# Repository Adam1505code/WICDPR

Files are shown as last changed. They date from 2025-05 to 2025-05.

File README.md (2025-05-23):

# WICDPR: Winch-Integrated Cable-Driven Parallel Robots for Agriculture

## Project Overview

This repository contains the full open-source hardware, software, and documentation for both 2D and 3D Winch-Integrated Cable-Driven Parallel Robots (WICDPRs).  
These robots are designed for rapid deployment and high-precision motion in agricultural environments (e.g., greenhouses, field plots), minimizing soil compaction and maximizing flexibility by keeping all winches on the mobile platform.
## System Features

- **2D and 3D platforms:** Planar and spatial robots for different workspace needs.
- **Real-time feedback:** Rotary encoders and MPU6050 IMU for position and tilt.
- **Double-loop PID control:** Ziegler–Nichols tuned, with auto-leveling.
- **Teleoperation:** Manual control using ROS teleop nodes.
- **Safety:** E-stop support, tension checks, WiFi router for secure SSH.
- **Comprehensive docs:** Bills of Materials (BOM), STL files, wiring diagrams, and demo videos.

# Getting Started: Step-by-Step Setup for WICDPR

## 1. Hardware Assembly

### 2D System

1. **Print all required STL parts** (see [`docs/stl/`](docs/stl/)).
2. **Assemble the frame** with PETG parts, plywood sheets, M3 and M4 bolts, and ball bearings.
3. **Install NEMA-17 stepper motors and planetary gearboxes** as per mechanical drawings.
4. **Mount both rotary encoders** to the winch spools; ensure pull-up resistor adapters are installed.
5. **Attach the IMU (MPU6050)** securely on the platform for accurate roll/pitch sensing.
6. **String the braided fishing line** through all pulleys and attach to the anchors.
7. **Double-check all power and signal connections** using the wiring diagram.
8. **[Optional]** Place test load (marbles) on platform for load/stability testing.

> 2D Platform Render
> *Figure: 2D Platform CAD Render*

---

### 3D System

1. **Print and assemble all 3D parts** for platform, winch modules, and mounting brackets.
2. **Mount all four DC geared motors** and rotary encoders (DFRobot SEN0230) to winch modules.
3. **Install the IMU (MPU6050)** on the platform.
4. **Set up the winch pods** at each platform corner with swivel/lazy-susan bearings.
5. **String 20m of braided fishing line** for each cable, tension and secure at anchor points.
6. **Connect all electronics:**  
   - Arduino Mega (motor board), Arduino Uno (sensor board)
   - Dual 7A DC motor drivers (DFRobot DRI0041)
   - Pull-up adapters on each encoder
7. **Wire up power supplies, Pi 4, and WiFi router.**

> 3D Platform Assembly
> *Figure: 3D Platform with Electronics*

---

## 2. Electronics and Firmware

1. **Flash the sensor node code** (`arduino/arduino_encoder_revised.ino`) to the Arduino Uno.
2. **Flash the motor node code** (e.g., `arduino_motor_3d.ino` for 3D, or the correct 2D sketch) to the Arduino Mega (3D) or second Uno (2D).
3. **Insert formatted 64GB microSD cards** into the Pi(s).
4. **Power on all electronics** and connect Arduinos and Pi via USB cables.

---

## 3. Raspberry Pi and ROS Setup

1. **Connect the Pi to your WiFi router** (built-in or TP-Link USB adapter).
2. **SSH into the Pi** from your PC using its IP address:
   
   `ssh pi@<your_pi_ip_address>`
3. Source the ROS Noetic environment:
   `source /opt/ros/noetic/setup.bash`
4. Install all Python requirements:
   `pip3 install -r requirements.txt`
5. Start ROS core:
    `roscore`
6. Start ROS serial communication with the first Arduino:
    `rosrun rosserial_python serial_node.py _port:=/dev/ttyUSB0 _baud:=57600`
   
8. Start ROS serial communication with the second Arduino:
   `rosrun rosserial_python serial_node.py _port:=/dev/ttyUSB1 _baud:=57600`
   
10. Run the 2D WICDPR controller node:
    `python3 scripts/cable_platform_2d_controller.py`
    
12. Run the 3D WICDPR controller node:
   `python3 scripts/cable_platform_3d_controller.py`

10.Run 2D teleoperation:
   `python3 scripts/teleop_controller_2D.py`
   
11.Run 3D teleoperation:
    `python3 scripts/teleop_controller_3D.py`

## Bill of Materials (BOM)

- [2D_WICDPR_BOM.xlsx](docs/2D_WICDPR_BOM.xlsx)
- [3D_WICDPR_BOM.xlsx](docs/3D_WICDPR_BOM.xlsx)

*All components, suppliers, and links are included. Please check the BOM before assembly.*

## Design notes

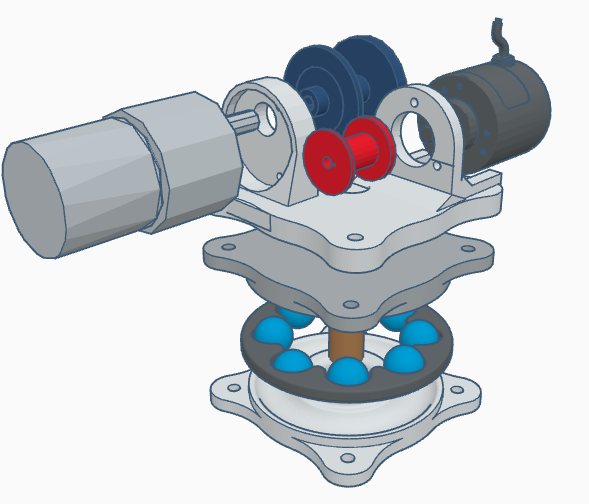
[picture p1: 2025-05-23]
doc/diagrams/Isometric_view_of_winch_design.png

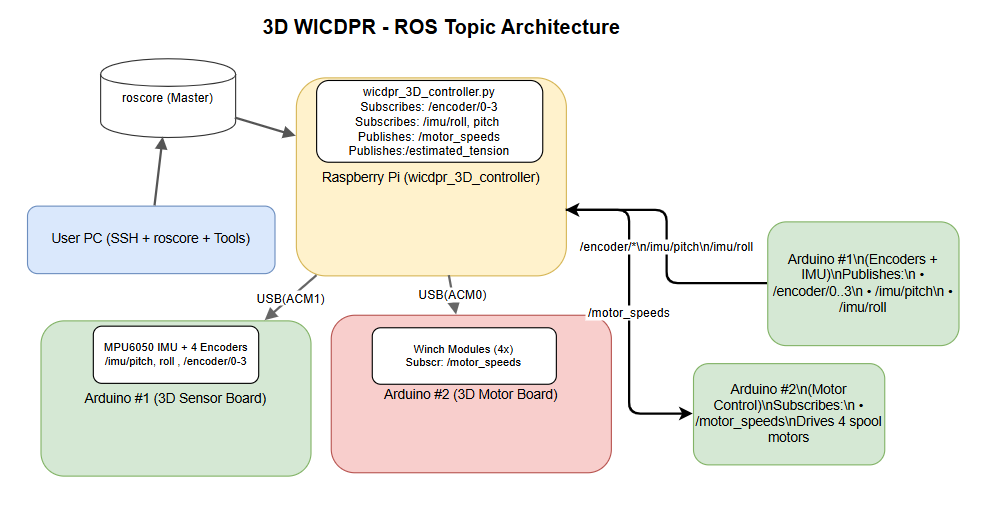
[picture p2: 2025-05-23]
doc/diagrams/ros_architecturefor3D.png

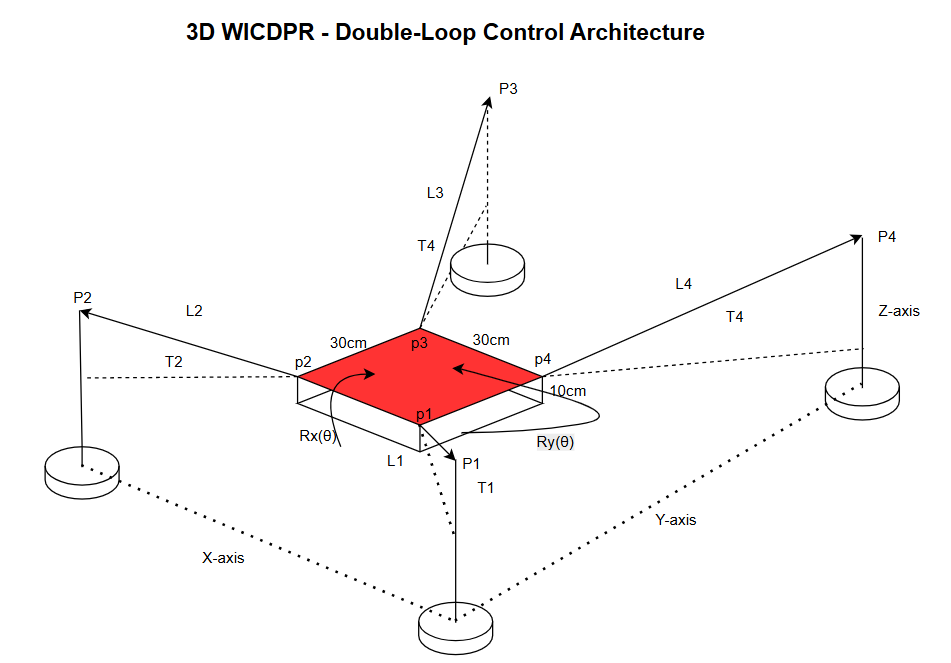
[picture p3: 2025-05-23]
doc/diagrams/Kinematics_of_the_3D_system.png

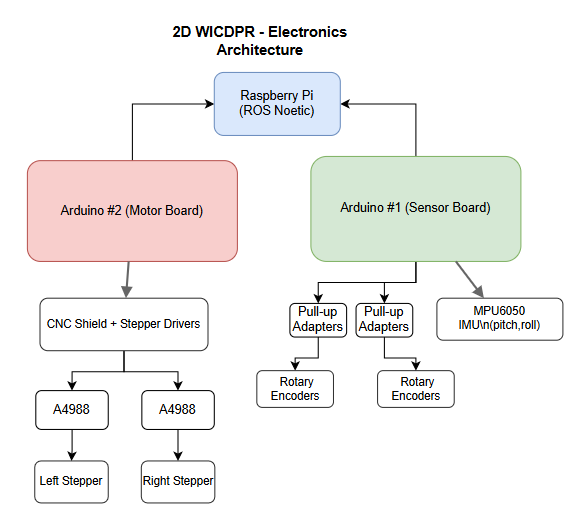
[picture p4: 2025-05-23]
doc/diagrams/2D_WICPDR.png

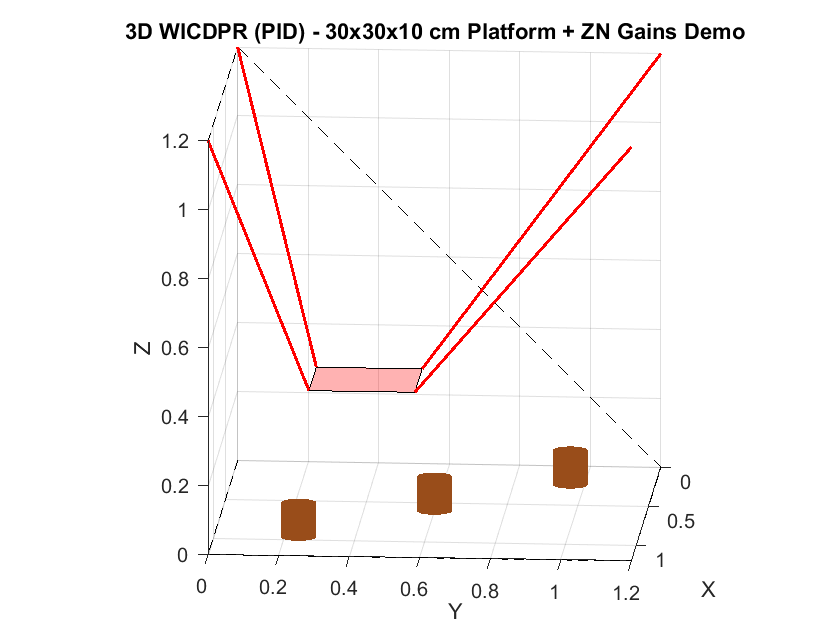
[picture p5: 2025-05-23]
doc/diagrams/ideal_response_of_3d_system.png

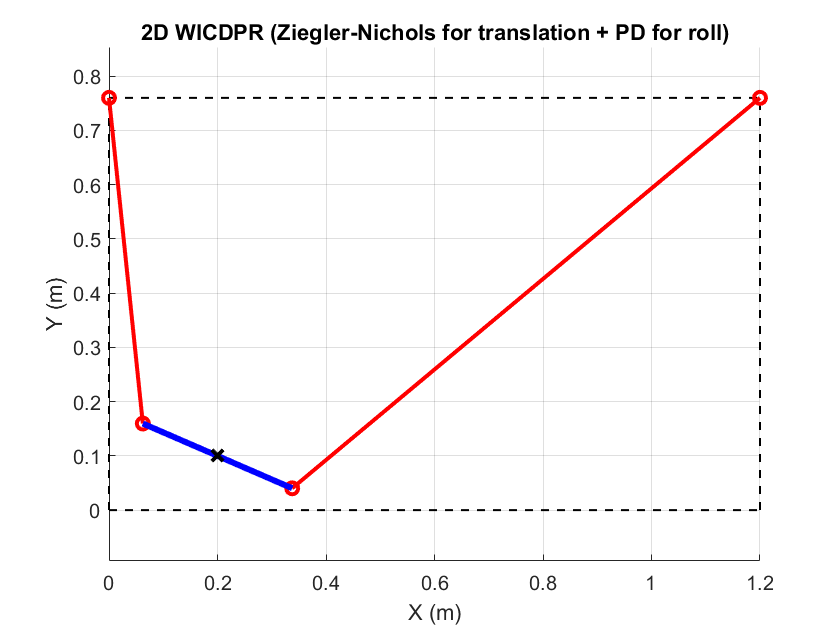
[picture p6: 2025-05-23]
doc/diagrams/2D Simulation.png

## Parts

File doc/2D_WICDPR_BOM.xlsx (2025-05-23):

Component | Quantity | Supplier/Link | Notes/Source
PETG Filament | 1.1 kg | https://www.amazon.com/s?k=petg+filament | 3D printed frame and parts
M3 Bolts and Washers | 24 | https://www.amazon.com/s?k=m3+bolts+and+washers | For frame/platform assembly
NEMA-17 Stepper Motor + Planetary Gearbox + CNC Shield + A4988 + Cables (Kit) | 1 kit | https://www.amazon.co.uk/Professional-Printer-CNC-Shield-Expansion-Engraving/dp/B0D65MFN4V/ | Motors, drivers, cables, shield
Arduino Uno (RS) | 2 | https://uk.rs-online.com/web/p/processor-microcontroller-development-kits/7697414 | Motor node + sensor node
Photoelectric Rotary Encoder (DFRobot SEN0230) | 2 | https://wiki.dfrobot.com/Incremental_Photoelectric_Rotary_Encoder_-_400P_R_SKU__SEN0230 | Cable length feedback
Pull-up Resistor Adapter | 2 | https://www.dfrobot.com/product-1626.html | For each encoder
Ball Bearing | 8 | https://www.amazon.com/s?k=ball+bearing+608zz | For drum/axle support
Braided Hercules Fishing Line | 10 m | https://www.amazon.com/HERCULES-Braided-Fishing-Tension-100lb-109yds/dp/B01J4MHR50 | Main cable, 0.1–0.3mm
Raspberry Pi 3B+ | 1 | https://www.raspberrypi.com/products/raspberry-pi-3-model-b-plus/ | ROS master/controller
TP-Link WiFi Adapter (USB) | 1 | https://www.amazon.com/s?k=tp-link+wifi+adapter | For Pi wireless/SSH
USB Cable (Arduino to Pi) | 2 | https://www.amazon.com/AmazonBasics-USB-2-0-Cable-Male/dp/B00NH11KIK | Arduino <-> Pi
Raspberry Pi Power Supply (USB-C) | 1 | https://www.amazon.com/s?k=raspberry+pi+usb-c+power+supply | 5V 3A
M4 Bolts | 20 | https://www.amazon.com/s?k=m4+bolts | Frame, assembly
DC Barrel Jack Pigtail (5.5mm x 2.1mm) | 1 | https://www.amazon.com/Male-Female-Barrel-Connector-Adapter/dp/B07YCK13BV | For power adapters
Plywood Sheet (30cm x 10cm x 8mm) | 2 | https://www.homedepot.com/p/Handprint-1-4-in-x-2-ft-x-4-ft-Sande-Plywood-25379/206883644 | Platform and frame
IMU (MPU6050) | 1 | https://www.amazon.co.uk/AZDelivery-MPU-6050-Gyroscope-Accelerometer-including/dp/B07TKLYBD6 | For roll/pitch feedback
SanDisk 64GB microSDXC (for Raspberry Pi) | 2 | https://www.amazon.co.uk/SanDisk-Extreme-microSDXC-RescuePRO-Performance/dp/B09X7C7LL1/ref=sr_1_6 | For Raspberry Pi OS, ROS, and data logging
WiFi Router (Dual-Band) | 1 | https://www.amazon.co.uk/s?k=wifi+router | For secure SSH and remote ROS access to Raspberry Pi
Marbles | 1 bag | Art & Hobby | For platform load test

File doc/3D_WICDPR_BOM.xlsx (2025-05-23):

Component | Quantity | Supplier/Link | Notes/Source
12V Metal DC Geared Motor with Encoder (131:1, 83RPM) | 4 | https://www.dfrobot.com/product-633.html | Main winch actuator, with encoder
Incremental Photoelectric Rotary Encoder (DFRobot SEN0230) | 4 | https://wiki.dfrobot.com/Incremental_Photoelectric_Rotary_Encoder_-_400P_R_SKU__SEN0230 | Cable length feedback
Pull-up Resistor Adapter for Sensors | 6 | https://www.dfrobot.com/product-1626.html | For encoder signal integrity
Dual 7A DC Motor Driver Board (DFRobot DRI0041) | 2 | https://wiki.dfrobot.com/7A_Dual_DC_Motor_Driver_SKU__DRI0041 | Drives two DC motors each
IMU (MPU6050 Gyroscope + Accelerometer) | 2 | https://www.amazon.co.uk/AZDelivery-MPU-6050-Gyroscope-Accelerometer-including/dp/B07TKLYBD6 | For platform orientation
Arduino Mega 2560 (RS) | 1 | https://uk.rs-online.com/web/p/processor-microcontroller-development-kits/6961662 | Motor controller node
Arduino Uno (RS) | 1 | https://uk.rs-online.com/web/p/processor-microcontroller-development-kits/7697414 | Sensor node
Raspberry Pi 4B+ | 1 | https://www.raspberrypi.com/products/raspberry-pi-4-model-b/ | ROS master/controller
Raspberry Pi Power Supply (USB-C, 5V 3A) | 1 | https://www.amazon.com/s?k=raspberry+pi+usb-c+power+supply | For Pi
TP-Link WiFi Adapter (USB) | 1 | https://www.amazon.com/s?k=tp-link+wifi+adapter | For Pi wireless/SSH
Power Supply for Motors (12V 6A or 24V 10A) | 1 | https://www.amazon.com/s?k=12v+6a+power+supply | Main supply for winches
Ball Bearing | 8 | https://www.amazon.com/s?k=ball+bearing+608zz | For winch drums
Braided Hercules Fishing Line | 20 m | https://www.amazon.co.uk/HERCULES-100m-2000m-10lb-300lb-Multifilament-Freshwater/dp/B0791F5XJG?th=1 | Main cable, 0.1–0.3mm, >650N
Plywood Sheet (30cm x 30cm x 8mm) | 1 | https://www.homedepot.com/p/Handprint-1-4-in-x-2-ft-x-4-ft-Sande-Plywood-25379/206883644 | Platform deck
PETG Filament | 1.2 kg | https://www.amazon.com/s?k=petg+filament | 3D printed parts
M3 Bolts and Washers | 24 | https://www.amazon.com/s?k=m3+bolts+and+washers | For frame and mounts
Swivel/Lazy-Susan Bearing | 4 | https://www.amazon.com/s?k=lazy+susan+bearing | For winch mounts
USB Cable (A-B for Arduino) | 2 | https://www.amazon.com/AmazonBasics-USB-2-0-Cable-Male/dp/B00NH11KIK | Arduino <-> Pi
SanDisk 64GB microSDXC (for Raspberry Pi) | 2 | https://www.amazon.co.uk/SanDisk-Extreme-microSDXC-RescuePRO-Performance/dp/B09X7C7LL1/ref=sr_1_6 | For Raspberry Pi OS, ROS, and data logging
WiFi Router (Dual-Band) | 1 | https://www.amazon.co.uk/s?k=wifi+router | For secure SSH and remote ROS access to Raspberry Pi
Marbles | 1 bag | Art & Hobby | For platform load test

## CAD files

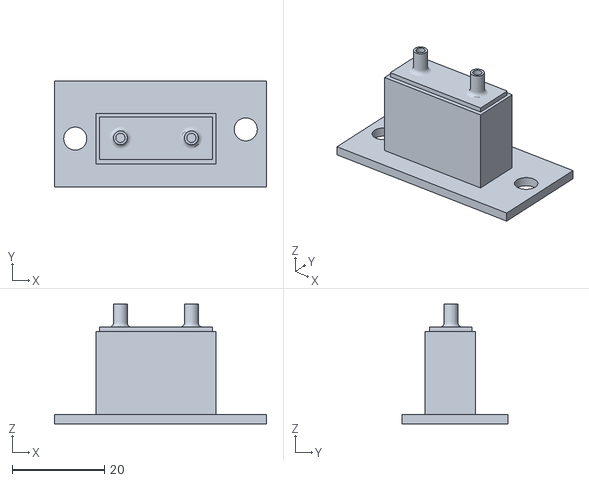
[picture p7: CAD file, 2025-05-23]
stl/IMU_Holder_bracket.stl
46.0 x 23.0 x 26.0

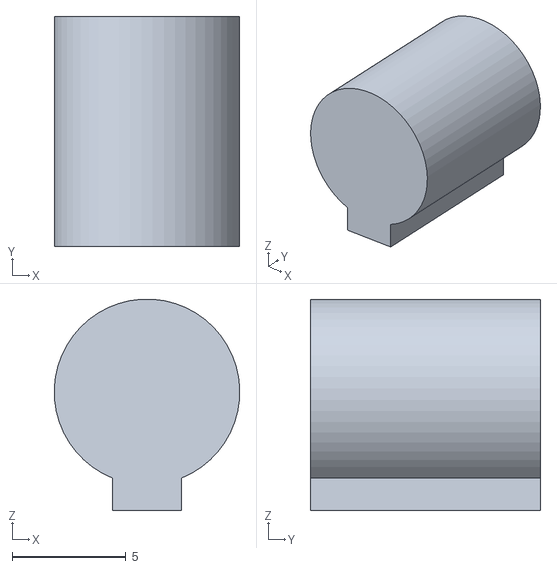
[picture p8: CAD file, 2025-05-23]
stl/measurement_of_key_way_slot.STL
8.15 x 10.1 x 9.28

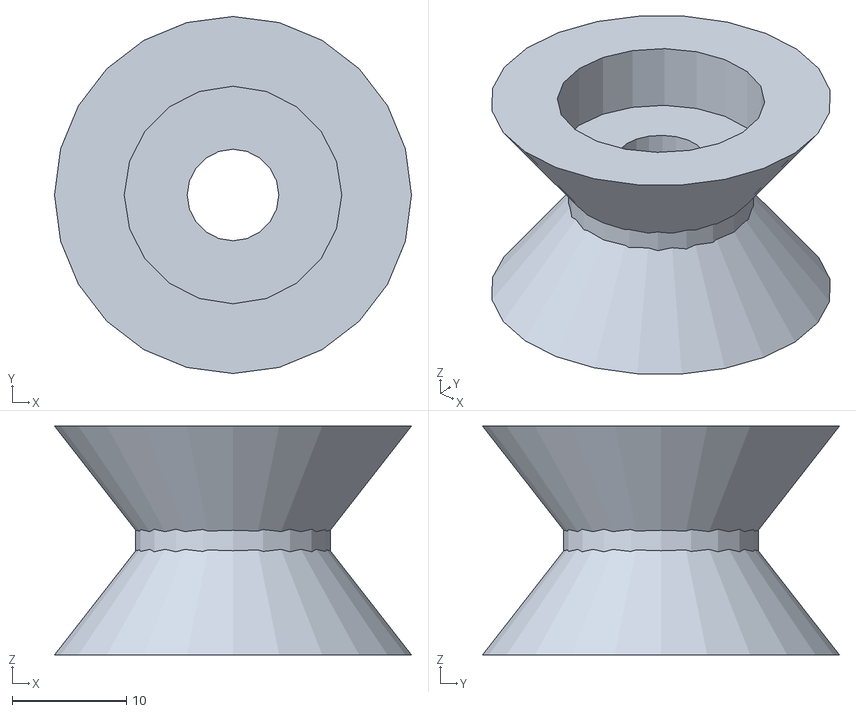
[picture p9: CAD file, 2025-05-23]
stl/2D_pulley_design_for_bearings.stl
31.2 x 31.2 x 20.0

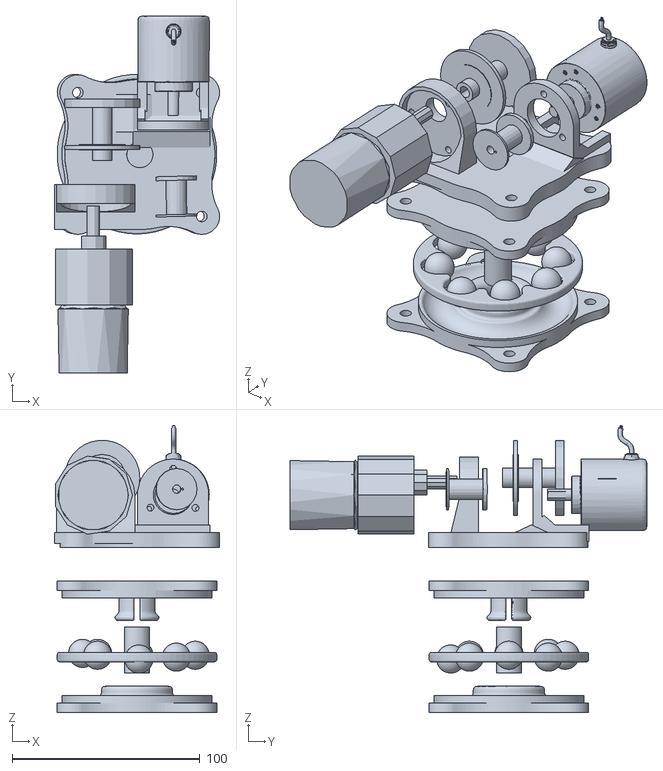
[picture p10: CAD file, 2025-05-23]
stl/3D-WINCH-INTEGRATED-LAZY-SUSAN.stl
88.0 x 190.0 x 152.9

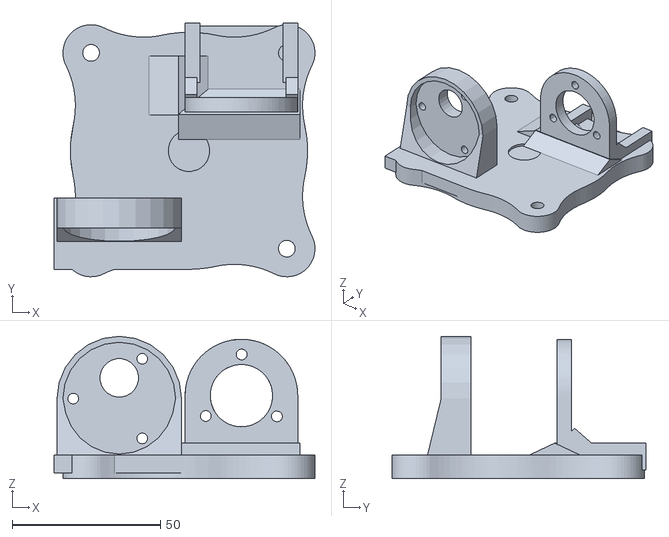
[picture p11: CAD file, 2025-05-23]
stl/3D-motor_and_rotary_encoder_bracket.stl
88.0 x 85.5 x 48.0

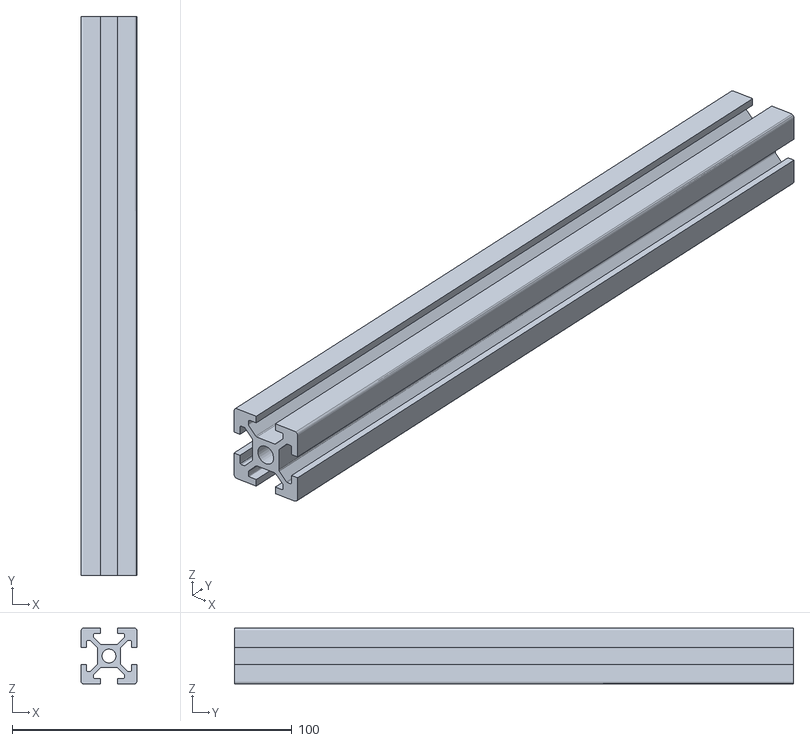
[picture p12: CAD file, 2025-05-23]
stl/long_Extrusion_piece.stl
20.0 x 200.0 x 20.0

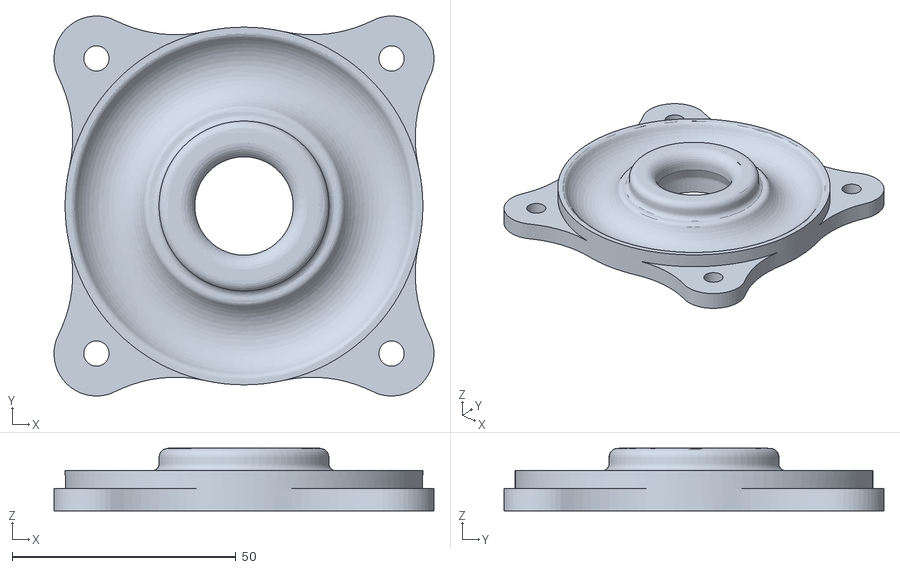
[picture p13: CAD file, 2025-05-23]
stl/3D-bottom_part_lazy_susan.stl
85.0 x 85.0 x 14.0

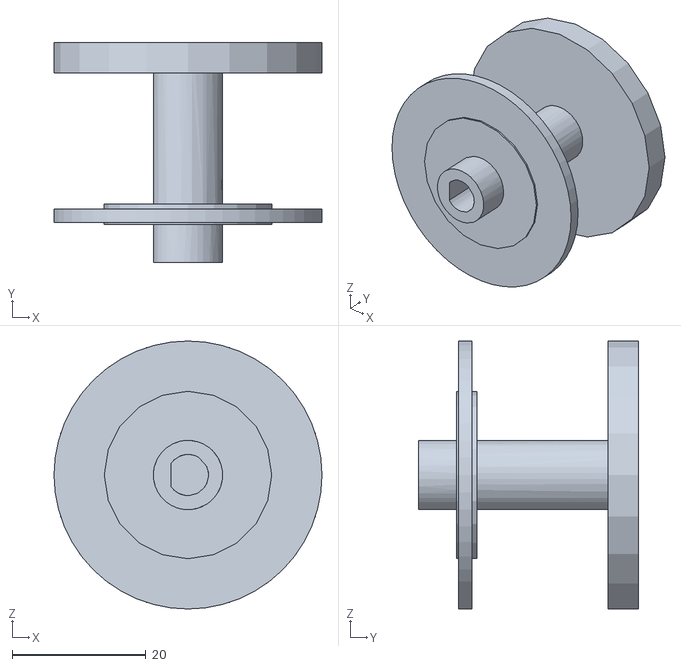
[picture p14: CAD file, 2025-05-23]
stl/3D-Winch.stl
40.0 x 32.9 x 40.0

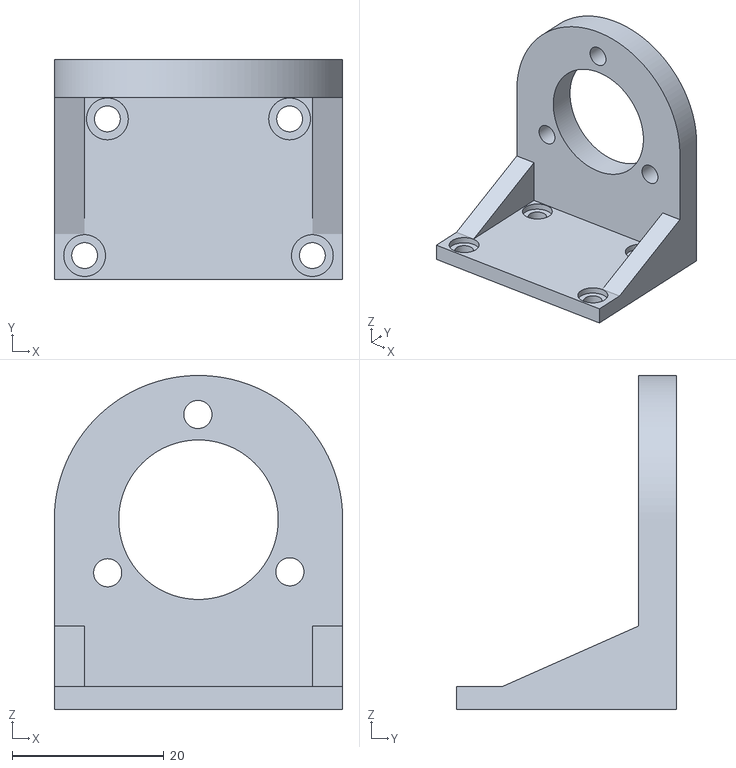
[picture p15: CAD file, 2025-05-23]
stl/rotary_encoder_mount.stl
38.0 x 29.0 x 44.0

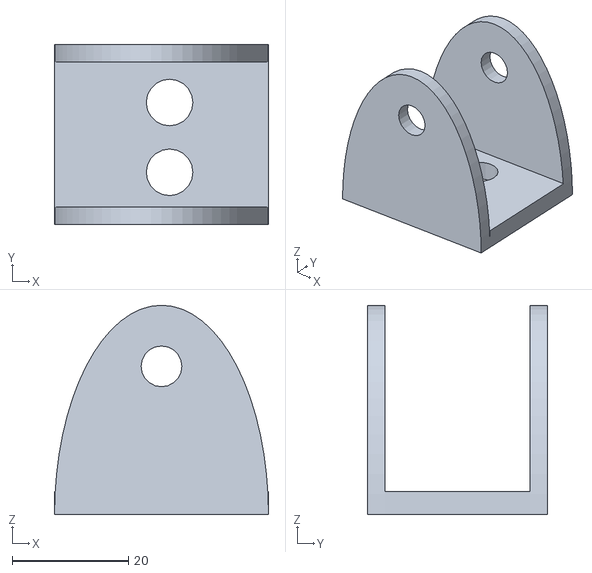
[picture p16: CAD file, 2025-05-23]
stl/Pulley_holder_mount.stl
36.8 x 31.0 x 36.0

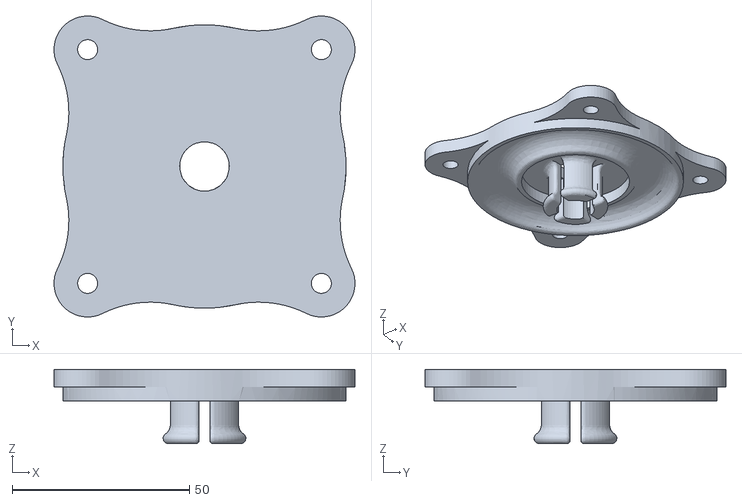
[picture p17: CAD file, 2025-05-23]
stl/3D-Lazy_Susan_top_piece.stl
85.0 x 85.0 x 21.0

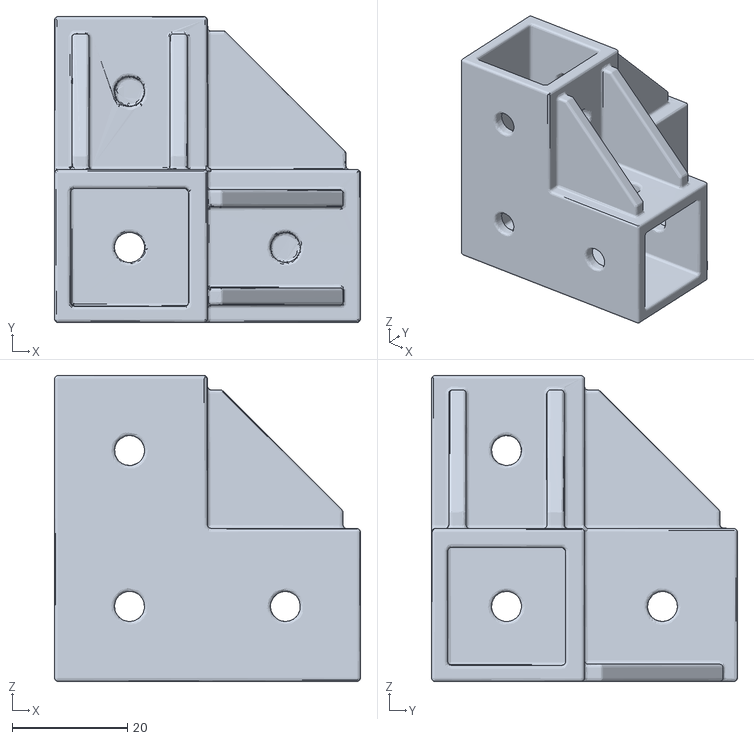
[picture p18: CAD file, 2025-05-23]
stl/Corner_Extrusion_Bracket.stl
53.0 x 53.0 x 53.0

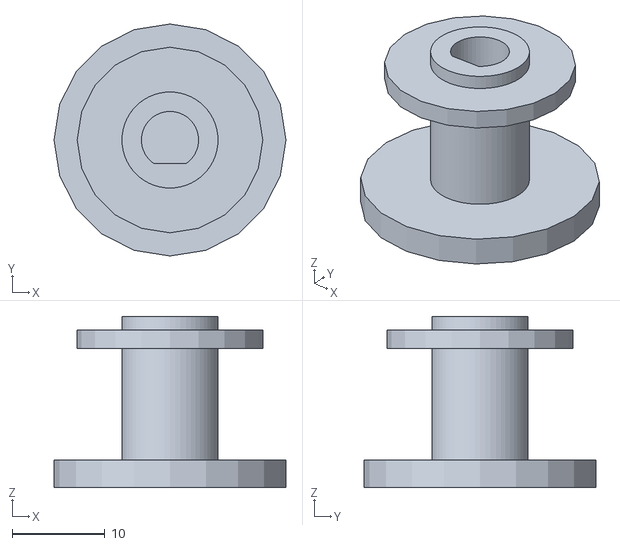
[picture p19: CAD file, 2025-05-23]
stl/Rotary_encoder_pulley.stl
25.0 x 25.0 x 18.5

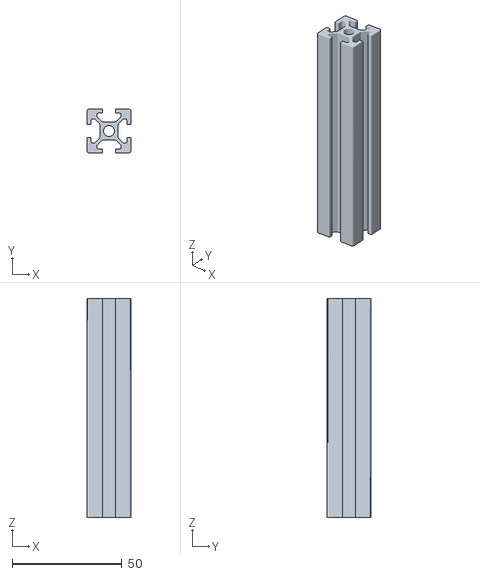
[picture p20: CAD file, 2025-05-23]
stl/Shorter_piece_Extrusion.stl
20.0 x 20.0 x 100.0

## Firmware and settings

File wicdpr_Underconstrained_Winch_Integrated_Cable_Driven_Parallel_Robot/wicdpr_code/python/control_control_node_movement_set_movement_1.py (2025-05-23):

#!/usr/bin/env python3
import rospy
import numpy as np
import csv
from datetime import datetime
from std_msgs.msg import Float32, Int32MultiArray, Bool
from geometry_msgs.msg import Vector3
# from pidautotune import PIDAutotune  # Not strictly needed if we're just assigning Z-N gains directly

class CablePlatform3DController:
    def __init__(self):
        # Configuration parameters
        self.config = {
            'workspace': {
                'width': 1.3,    # x-dimension (meters)
                'depth': 1.3,     # y-dimension (meters)
                'height': 0.76    # z-dimension (meters)
            },
            'platform': {
                'width': 0.3,     # x-dimension (meters)
                'depth': 0.3,     # y-dimension (meters)
                'mass': 2.7,      # kg
                'start_pos': [0.65, 0.65, 0.38]  # [x, y, z]
            },
            'motors': {
                'layout': {
                    1: 'front-right',
                    2: 'front-left',
                    3: 'rear-left',
                    4: 'rear-right'
                },
                'max_speed': 50
            },
            'safety': {
                'e_stop_topic': '/emergency_stop',
                'max_tension': 100  # Newtons (safety threshold)
            },
            'logging': {
                'enabled': True,
                'filename': f'platform_log_{datetime.now().strftime("%Y%m%d_%H%M%S")}.csv'
            }
        }

        # System state
        self.g = 9.81
        self.e_stop = False
        self.cable_lengths = [0, 0, 0, 0]  # [fr, fl, rl, rr]
        self.orientation = {'pitch': 0, 'roll': 0}
        self.platform_pos = self.config['platform']['start_pos']

        # -------- ZIEGLER–NICHOLS PID GAINS (shared by pitch & roll) --------
        # Suppose Ku=2.0, Pu=1.0:
        #   Kp = 0.6*Ku=1.2
        #   Ki = 2*(0.6*Ku)/Pu=2.4
        #   Kd = 0.075*Ku*Pu=0.15
        Ku = 2.0
        Pu = 1.0
        zn_kp = 0.6 * Ku  # 1.2
        zn_ki = 2.0 * zn_kp / Pu  # 2.4
        zn_kd = 0.075 * Ku * Pu   # 0.15

        # Assign them to pitch and roll
        self.pid_gains = {
            'pitch': {'kp': zn_kp, 'ki': zn_ki, 'kd': zn_kd},
            'roll':  {'kp': zn_kp, 'ki': zn_ki, 'kd': zn_kd}
        }

        # PID integrator states
        self.integral_errors = {'pitch': 0, 'roll': 0}
        self.last_errors = {'pitch': 0, 'roll': 0}

        # ROS initialization
        rospy.init_node('platform_3d_controller')
        self.setup_ros_communications()

        # Data logging
        if self.config['logging']['enabled']:
            self.setup_data_logging()

        rospy.loginfo("3D Controller initialized with configuration:")
        rospy.loginfo(f"Workspace: {self.config['workspace']}")
        rospy.loginfo(f"Platform: {self.config['platform']}")
        rospy.loginfo(f"Motor layout: {self.config['motors']['layout']}")

        rospy.loginfo("Using Ziegler–Nichols PID Gains => "
                      f"Kp={zn_kp:.2f}, Ki={zn_ki:.2f}, Kd={zn_kd:.2f} "
                      "(pitch & roll)")

    def setup_ros_communications(self):
        # Subscribers
        rospy.Subscriber('/imu/pitch', Float32, self.pitch_callback)
        rospy.Subscriber('/imu/roll', Float32, self.roll_callback)
        rospy.Subscriber('/encoder/0', Float32, self.fr_encoder_callback)  # Front-right
        rospy.Subscriber('/encoder/1', Float32, self.fl_encoder_callback)  # Front-left
        rospy.Subscriber('/encoder/2', Float32, self.rl_encoder_callback)  # Rear-left
        rospy.Subscriber('/encoder/3', Float32, self.rr_encoder_callback)  # Rear-right
        rospy.Subscriber(self.config['safety']['e_stop_topic'], Bool, self.e_stop_callback)

        # Publishers
        self.motor_pub = rospy.Publisher('/motor_speeds', Int32MultiArray, queue_size=10)
        self.status_pub = rospy.Publisher('/controller_status', Vector3, queue_size=10)
        self.tension_pub = rospy.Publisher('/cable_tensions', Float32, queue_size=10)

    def setup_data_logging(self):
        self.log_file = open(self.config['logging']['filename'], 'w')
        self.log_writer = csv.writer(self.log_file)
        headers = [
            'timestamp', 'pos_x', 'pos_y', 'pos_z',
            'pitch', 'roll', 'tension_fr', 'tension_fl',
            'tension_rl', 'tension_rr', 'motor_fr', 'motor_fl',
            'motor_rl', 'motor_rr', 'pid_pitch_kp', 'pid_pitch_ki',
            'pid_pitch_kd', 'pid_roll_kp', 'pid_roll_ki', 'pid_roll_kd'
        ]
        self.log_writer.writerow(headers)
        rospy.loginfo(f"Data logging to {self.config['logging']['filename']}")

    def log_data(self):
        if not self.config['logging']['enabled']:
            return

        data = [
            rospy.get_time(),
            self.platform_pos[0],
            self.platform_pos[1],
            self.platform_pos[2],
            np.rad2deg(self.orientation['pitch']),
            np.rad2deg(self.orientation['roll']),
            *getattr(self, 'current_tensions', [0,0,0,0]),  # if not defined yet, default
            *getattr(self, 'last_motor_cmd', [0,0,0,0]),
            self.pid_gains['pitch']['kp'],
            self.pid_gains['pitch']['ki'],
            self.pid_gains['pitch']['kd'],
            self.pid_gains['roll']['kp'],
            self.pid_gains['roll']['ki'],
            self.pid_gains['roll']['kd']
        ]
        self.log_writer.writerow(data)
        self.log_file.flush()

    def pitch_callback(self, msg):
        self.orientation['pitch'] = np.deg2rad(msg.data)
        self.report_status("IMU", f"Pitch: {msg.data:.2f}°")

    def roll_callback(self, msg):
        self.orientation['roll'] = np.deg2rad(msg.data)
        self.report_status("IMU", f"Roll: {msg.data:.2f}°")

    def fr_encoder_callback(self, msg):
        self.cable_lengths[0] = msg.data * 0.001  # Front-right
        self.report_status("Encoder FR", f"Length: {self.cable_lengths[0]:.3f}m")

    def fl_encoder_callback(self, msg):
        self.cable_lengths[1] = msg.data * 0.001  # Front-left
        self.report_status("Encoder FL", f"Length: {self.cable_lengths[1]:.3f}m")

    def rl_encoder_callback(self, msg):
        self.cable_lengths[2] = msg.data * 0.001  # Rear-left
        self.report_status("Encoder RL", f"Length: {self.cable_lengths[2]:.3f}m")

    def rr_encoder_callback(self, msg):
        self.cable_lengths[3] = msg.data * 0.001  # Rear-right
        self.report_status("Encoder RR", f"Length: {self.cable_lengths[3]:.3f}m")

    def e_stop_callback(self, msg):
        self.e_stop = msg.data
        if self.e_stop:
            self.send_motor_command([0, 0, 0, 0])
            rospy.logerr("!!! EMERGENCY STOP ACTIVATED !!!")
        else:
            rospy.logwarn("Emergency stop released")

    def report_status(self, source, message):
        status_msg = Vector3()
        status_msg.x = rospy.get_time()
        status_msg.y = hash(source) % 1000
        status_msg.z = hash(message) % 1000
        self.status_pub.publish(status_msg)
        rospy.loginfo(f"[{source}] {message}")

    def calculate_position(self):
        """3D forward kinematics using cable lengths (simplified)."""
        anchors = np.array([
            [self.config['workspace']['width'], 0, self.config['workspace']['height']],  # FR
            [0, 0, self.config['workspace']['height']],                                  # FL
            [0, self.config['workspace']['depth'], self.config['workspace']['height']],  # RL
            [self.config['workspace']['width'], self.config['workspace']['depth'], self.config['workspace']['height']]  # RR
        ])
        # Very simplified approach: average anchor coords minus cable lengths:
        x = np.mean([a[0] for a in anchors])
        y = np.mean([a[1] for a in anchors])
        z = np.mean([a[2] - l for a, l in zip(anchors, self.cable_lengths)])
        self.platform_pos = [x, y, z]

    def calculate_tensions(self):
        """Compute cable tensions using 3D static equilibrium (simplified)."""
        anchors = np.array([
            [self.config['workspace']['width'], 0, self.config['workspace']['height']],  # FR
            [0, 0, self.config['workspace']['height']],                                  # FL
            [0, self.config['workspace']['depth'], self.config['workspace']['height']],  # RL
            [self.config['workspace']['width'], self.config['workspace']['depth'], self.config['workspace']['height']]  # RR
        ])
        platform_corners = np.array([
            [self.platform_pos[0] + 0.15, self.platform_pos[1] - 0.15, self.platform_pos[2]],
            [self.platform_pos[0] - 0.15, self.platform_pos[1] - 0.15, self.platform_pos[2]],
            [self.platform_pos[0] - 0.15, self.platform_pos[1] + 0.15, self.platform_pos[2]],
            [self.platform_pos[0] + 0.15, self.platform_pos[1] + 0.15, self.platform_pos[2]]
        ])
        cable_vectors = anchors - platform_corners
        norms = np.linalg.norm(cable_vectors, axis=1)
        unit_vectors = cable_vectors / norms[:, np.newaxis]

        A = np.vstack([unit_vectors.T,
                       np.cross(platform_corners - self.platform_pos, unit_vectors).T])
        b = np.array([0, 0, self.config['platform']['mass'] * self.g, 0, 0, 0])

        tensions = np.linalg.pinv(A) @ b
        tensions = np.clip(tensions, 0, self.config['safety']['max_tension'])
        self.current_tensions = tensions
        return tensions

    def tilt_compensation(self):
        """Apply the Z-N PID on pitch & roll."""
        corrections = {}
        for axis in ['pitch', 'roll']:
            error = -self.orientation[axis]  # Negative to oppose tilt
            # PID terms
            P = self.pid_gains[axis]['kp'] * error
            self.integral_errors[axis] += error
            I = self.pid_gains[axis]['ki'] * self.integral_errors[axis]
            D = self.pid_gains[axis]['kd'] * (error - self.last_errors[axis])
            self.last_errors[axis] = error
            corrections[axis] = P + I + D

        # Motor corrections [FR, FL, RL, RR]
        motor_corrections = [
            corrections['pitch'] - corrections['roll'],   # front-right
            corrections['pitch'] + corrections['roll'],   # front-left
            -corrections['pitch'] + corrections['roll'],  # rear-left
            -corrections['pitch'] - corrections['roll']   # rear-right
        ]
        return motor_corrections

    def send_motor_command(self, speeds):
        """Send speed commands (Int32MultiArray) to /motor_speeds, with E-stop & clipping."""
        if self.e_stop:
            speeds = [0, 0, 0, 0]

        speeds = [int(np.clip(s, -self.config['motors']['max_speed'],
                              self.config['motors']['max_speed'])) for s in speeds]

        cmd = Int32MultiArray()
        cmd.data = speeds
        self.motor_pub.publish(cmd)
        self.last_motor_cmd = speeds

        self.report_status("Motor Cmd",
                           f"FR={speeds[0]}, FL={speeds[1]}, RL={speeds[2]}, RR={speeds[3]}")

    def run(self):
        rate = rospy.Rate(50)  # 50Hz control loop
        try:
            while not rospy.is_shutdown():
                if not self.e_stop:
                    # 1) Position (very simple approximate)
                    self.calculate_position()
                    # 2) Tensions
                    tensions = self.calculate_tensions()
                    if any(t > self.config['safety']['max_tension'] for t in tensions):
                        rospy.logwarn(f"High tension: {tensions}")
                        self.send_motor_command([0, 0, 0, 0])
                        rate.sleep()
                        continue
                    # 3) tilt compensation
                    corr = self.tilt_compensation()
                    base_speed = 0  # can be changed for actual movement
                    motor_speeds = [base_speed + c for c in corr]
                    # 4) send
                    self.send_motor_command(motor_speeds)
                # 5) log
                self.log_data()
                rate.sleep()
        except rospy.ROSInterruptException:
            pass
        finally:
            if self.config['logging']['enabled']:
                self.log_file.close()
            self.send_motor_command([0,0,0,0])
            rospy.loginfo("Controller shutdown complete")

if __name__ == '__main__':
    try:
        controller = CablePlatform3DController()
        controller.run()
    except Exception as e:
        rospy.logerr(f"Controller error: {str(e)}")

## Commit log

2025-05-23 Initial commit: Add all core WICDPR code (2D and 3D Arduino, ROS, Teleop)
    This upload includes all the main code used for the Winch-Integrated Cable-Driven Parallel Robot project: sensor nodes, motor nodes, and teleop scripts for both 2D and 3D systems.
2025-05-23 Commit_BOM
    commit contains BOM for all components required to create the 2 WICDPR Systems.
    [2D_WICDPR_BOM.xlsx, 3D_WICDPR_BOM.xlsx]
2025-05-23 stl_commit
    this commit contains all the 3D printed parts in my project.
    [2D_pulley_design_for_bearings.stl, 3D-Lazy_Susan_top_piece.stl, 3D-WINCH-INTEGRATED-LAZY-SUSAN.stl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]
2025-05-23 Commit Documents which outline design and Results Visually
    [2D_WICDPR_BOM.xlsx, 3D_WICDPR_BOM.xlsx]
